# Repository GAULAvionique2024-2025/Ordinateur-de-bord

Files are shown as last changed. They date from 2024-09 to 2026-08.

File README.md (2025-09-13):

# Ordinateur de Bord GAUL — Branche ODBlix

Bienvenue dans la branche **ODBlix** du projet *Ordinateur de Bord* de GAULAvionique.  
Cette version propose une architecture alternative / expérimentale / allégée (ajuster selon la réalité) du système embarqué, avec une organisation de dossier particulière et des versions de firmware différentes.

---

## Table des Matières

1. [Description générale](#description-générale)  
2. [Composants intégrés](#composants-intégrés)  
3. [Structure de la branche / organisation des dossiers](#structure-de-la-branche--organisation-des-dossiers)  
4. [Détails des versions](#détails-des-versions)  
5. [Installation & Build](#installation--build)  
6. [Roadmap & Fonctionnalités à venir](#roadmap--fonctionnalités-à-venir)  
7. [Contributeurs](#contributeurs)

---

## Description générale

La branche **ODBlix** propose une déclinaison de l’Ordinateur de Bord standard, conçue pour :

- réduire la complexité / le poids / la consommation (ajuster selon le but),
- tester de nouvelles versions expérimentales de firmware / de drivers,
- faciliter les comparaisons entre versions (V1, V3, etc.) dans un même environnement.

Elle s’appuie sur les mêmes principes que l’Ordinateur de Bord principal : collecte de données, télémétrie, enregistrement, communication, etc.

---

## Composants intégrés

ODBlix intègre (liste à vérifier selon ce qui est actif) :

- Accéléromètre / gyroscope  
- Capteur de pression / altimètre  
- Module GPS (position)  
- Lecteur de carte SD pour enregistrement de données  
- Module de communication radio pour la transmission vers le sol  
- Buzzer ou indicateurs sonores pour alertes / statuts  
- (Optionnel) capteurs auxiliaires selon version (température, orientation additionnelle, etc.)

---

## Structure de la branche / organisation des dossiers

Voici les principaux dossiers / fichiers, et leur rôle respectif :

| Dossier / fichier | Description |
|---|---|
| `ODB_V1/` | Version 1 du firmware / hardware : fonctionnalités de base, stabilité, tests initiaux. |
| `ODB_V2/` | Version 2 du firmware / hardware : stabilité, correction des problèmes de la V1 |
| `ODB_V3/` | Version 3 : ajout de fonctionnalités avancées / optimisation ; comparatif avec V2. |

---

## Détails des versions

- **ODB_V1** : version de base. Priorité sur la fiabilité et sur la collecte de données simples. Moins de fonctionnalités, interface minimale et non fonctionnel.
- **ODB_V2** : version de base. Priorité sur la fiabilité et sur la collecte de données simples. Moins de fonctionnalités, interface minimale avec correctifs, mais non testé.    
- **ODB_V3** : version plus avancée. Ajout / amélioration de modules, optimisations (ex : consommation, vitesse, taille), peut-être nouvelles fonctionnalités / capteurs.
- 
---

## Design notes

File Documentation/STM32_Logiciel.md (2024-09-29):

# 🧩 **Prise en main STM32CubeIDE**

## **STM32CubeIDE**

<div style="display: flex; justify-content: space-around;">
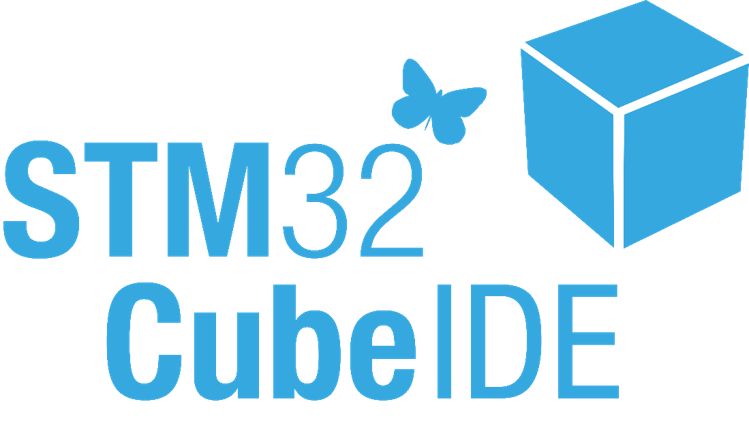
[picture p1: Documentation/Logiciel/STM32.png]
ODB1
  
</div>

STM32CubeIDE est un environnement de développement intégré (IDE) tout-en-un, qui inclut un compilateur, un éditeur de code, des outils de configuration de périphériques, ainsi que des outils de débogage.

## **Table des matières**
1. [Installation de STM32CubeIDE](#1-installation-de-stm32cubeide)
2. [Ouvrir un projet existant à partir de fichiers système](#2-ouvrir-un-projet-existant-à-partir-de-fichiers-système)
3. [Exploration de la structure des fichiers](#3-exploration-de-la-structure-des-fichiers)
4. [Consoles Problems et Tasks](#4-consoles-problems-et-tasks)
5. [Outils de Build](#5-outils-de-build)
6. [Débogage avec ST-Link](#6-débogage-avec-st-link)
7. [Exécution et Flash du programme](#7-exécution-et-flash-du-programme)
8. [Autres indications importantes pour STM32CubeIDE](#8-autres-indications-importantes-pour-stm32cubeide)

## ⬇️ **1. Installation de STM32CubeIDE**
Avant tout, vous devez installer STM32CubeIDE. Il est [téléchargeable](https://www.st.com/en/development-tools/stm32cubeide.html) gratuitement sur le site de STMicroelectronics.
## 📂 **2. Ouvrir un projet existant à partir de fichiers système**

### Cloner un dépôt Git
- Si vous travaillez à partir d’un dépôt Git, clonez-le dans le répertoire choisi en utilisant un client Git comme **Git Bash** ou un autre outil tel que **GitHub Desktop**.

### Ouvrir le projet dans STM32CubeIDE
- **Lancer STM32CubeIDE**.
- Allez dans **File > Open Projects from File System...**.
- Cliquez sur **Directory** et naviguez jusqu'au dossier cloné (celui contenant les fichiers de votre projet STM32).
- STM32CubeIDE analysera les fichiers et proposera les projets disponibles. Sélectionnez le projet pertinent.

### Projets basés sur `.ioc` (STM32CubeMX)
Si votre projet contient un fichier `.ioc`, c'est un fichier de configuration utilisé par **STM32CubeMX**, qui est intégré dans STM32CubeIDE. Ouvrez ce fichier pour reconfigurer les périphériques et générer des fichiers de code source (HAL, LL, etc.) automatiquement (utile au début, mais le projet est développé en low level **LL**).

## 🔍 **3. Exploration de la structure des fichiers**
Lorsque le projet est chargé, STM32CubeIDE organise les fichiers dans l'onglet **Project Explorer**, habituellement tout à gauche de l'interface :

### Header files (.h)
- Vous trouverez ces fichiers dans le dossier **Inc/** ou **include/**. Ils contiennent les définitions, les prototypes de fonctions et les déclarations des structures de données.

### Source files (.c)
- Les fichiers source se trouvent dans le dossier **Src/**. C’est là où vous écrivez le code source (implémentation des fonctions, logique principale, etc.).

### Drivers
- Ce dossier contient des fichiers relatifs aux bibliothèques STM32, telles que les fichiers HAL (Hardware Abstraction Layer), CMSIS (Cortex Microcontroller Software Interface Standard) et LL (Low Layer).

### Middlewares
- Si le projet utilise des bibliothèques de middleware comme FreeRTOS, USB, ou LwIP, ces fichiers seront stockés ici.

## 📋 **4. Consoles "Problems" et "Tasks"**

### Console "Problems"
- La console **Problems** affiche les erreurs et avertissements détectés dans votre projet. Elle vous aide à identifier rapidement les problèmes de compilation et de configuration. 
- Vous pouvez accéder à cette console via **Window > Show View > Problems**.

### Console "Tasks"
- La console **Tasks** vous permet de gérer les tâches, les rappels et les TODOs (//TODO) dans votre code. Vous pouvez y ajouter des notes ou des éléments à vérifier. 
- Accédez à cette console via **Window > Show View > Tasks**. Cela vous aide à garder une trace des éléments à améliorer ou des fonctionnalités à implémenter dans votre projet à travers le code.

## 🛠️ **5. Outils de Build**
STM32CubeIDE utilise **GNU Make** pour construire (compiler et lier) le projet. Voici les étapes pour réaliser le build de votre projet :

### Build simple
- Pour compiler le projet, cliquez sur le bouton 🔨 (en haut) ou utilisez le raccourci **CTRL+B**.
- Cela déclenchera le processus de compilation, et vous verrez les sorties dans la console de build (en bas de l'IDE). Si des erreurs ou des avertissements sont générés, vous pourrez les consulter ici.

### Configuration du build
- Vous pouvez ajuster les options de compilation dans **Project > Properties > C/C++ Build > Settings**. Vous pouvez, par exemple, modifier les optimisations du compilateur (par défaut -0n) ou ajuster les options de debug.

## 🐛 **6. Débogage avec ST-Link**

### Connexion du ST-Link
Le **ST-Link** est un outil de débogage et de programmation pour les microcontrôleurs STM32.

1. **Brancher** le ST-Link à la carte STM32 et à votre PC via USB.
2. STM32CubeIDE détecte normalement automatiquement le ST-Link connecté.

### Configuration de l'interface de débogage
- Allez dans **Run > Debug Configurations**.
- Choisissez **STM32 Cortex-M C/C++ Application** puis sélectionnez la configuration de débogage.
- Dans l'onglet **Debugger**, assurez-vous que le **ST-Link** est sélectionné comme interface de débogage.
  - Interface : **SWD (Serial Wire Debug)** est généralement le protocole utilisé.
  - Console : **SWV ITM Data Console** est utile lorsque des données sont **printf** sur le bus USB de l'ordinateur connecté au Debugger.

### Lancer le débogage
- Cliquez sur l'icône 🐞 pour démarrer le mode débogage. Cela compile le projet (si nécessaire), télécharge le binaire sur la carte, et arrête le processeur au point d'entrée (généralement dans `main()`).
- Vous pouvez ensuite utiliser des fonctionnalités comme les **points d'arrêt**, **step into/over** (avancer pas à pas dans le code), inspecter les **variables**, la **mémoire**, les **registres**, etc.

## 🏃‍♂️ **7. Exécution et Flash du programme**

### Lancer le programme sans débogage
- Pour exécuter directement votre programme sans mode debug, cliquez sur le bouton ▶️ (vert) ou utilisez **CTRL+F11**.
- Le binaire sera flashé sur la carte et le programme démarrera immédiatement après le téléchargement.

## 🔔 **8. Autres indications importantes pour STM32CubeIDE**

### Générer du code avec STM32CubeMX
- Si vous avez un fichier `.ioc`, vous pouvez l'ouvrir et ajouter des périphériques, ajuster la configuration (comme les GPIO, Timers, UART, I2C, etc.), et générer à nouveau le code. STM32CubeIDE synchronisera automatiquement les fichiers générés avec votre projet.

### Exploration de la documentation
- STM32CubeIDE fournit une intégration avec **la documentation CMSIS** et **les fichiers HAL/LL**. Faites un **CTRL+LMB** sur une fonction pour accéder directement à sa définition ou documentation dans le code.

---

🔙 Retour à la [page principale](../README.md)

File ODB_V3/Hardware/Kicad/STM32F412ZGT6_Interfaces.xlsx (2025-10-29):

Interface | #No | Horloge | Vitesse max | Fonctions | Broche | GPIO Mode | AFR | Fonctionnalités utiles | Informations
SPI | 1 | APB2 | 50Mbits/s | SCK | PA5 | Alternate | AF5 | FSMC | 8-16bits data bus width
 |  |  |  | MISO | PA6 | Alternate | AF5 |  | FSMC_CLK 90MHz
 |  |  |  | MOSI | PA7 | Alternate | AF5 | CRC | 32bits embdeed
 |  |  |  | NSS (CS) | PA4 | Alternate | AF5 | DMA | DMA1, DMA2 8 channels
 | 2 | APB1 | 25Mbits/s | SCK | PB13 | Alternate | AF5 |  | circular buffer embdeed
 |  |  |  | MISO | PB14 | Alternate | AF5 | NVIC | internal interrupt 16 lines
 |  |  |  | MOSI | PB15 | Alternate | AF5 | EXTI | external interrupt
 |  |  |  | NSS (CS) | PB12 | Alternate | AF5 | Timers | TIM1 - 4 channels | PA8,..,PA11
 | 3 | APB1 | 25Mbits/s | SCK | PB3 | Alternate | AF6 |  | TIM2 - 4 channel | PA0,…,PA3
 |  |  |  | MISO | PB4 | Alternate | AF6 |  | TIM3 - 4 chhanels | PC6,…,PC9
 |  |  |  | MOSI | PB5 | Alternate | AF6 |  | TIM4 - 4 chhanels | PB6,…, PB9
 |  |  |  | NSS (CS) | PA15 | Alternate | AF6 |  | TIM5 - 4 chhanels | PA0,…,PA3
 | 4 | APB2 | 50Mbits/s | SCK | PE12 | Alternate | AF5 |  | TIM8 - 4 chhanels | PC6,…,PC9
 |  |  |  | MISO | PE13 | Alternate | AF5 |  | TIM9 - 2 chhanels | PA2, PA3
 |  |  |  | MOSI | PE14 | Alternate | AF5 |  | TIM10 | PB8
 |  |  |  | NSS (CS) | PE4 | Alternate | AF5 |  | TIM11 | PB9
 | 5 | APB2 | 50Mbits/s | SCK | PB0 | Alternate | AF6 |  | TIM12 - 2 chhanels | PB14,PB15
 |  |  |  | MISO | PA12 | Alternate | AF6 |  | TIM13 | PA6
 |  |  |  | MOSI | PA10 | Alternate | AF6 |  | TIM14 | PA7
 |  |  |  | NSS (CS) | PA4 | Alternate | AF6
UART | 1 | APB2 | 12.5Mbit/s | TX | PA9 | Alternate | AF7
 |  |  |  | RX | PA10 | Alternate | AF7
 |  |  |  | CTS | PA11 | Alternate | AF7
 |  |  |  | RTS | PA12 | Alternate | AF7
 |  |  |  | CK | PA8 | Alternate | AF7 | RTC
 | 2 | APB1 | 6.25Mbit/s | TX | PD5 | Alternate | AF7
 |  |  |  | RX | PD6 | Alternate | AF7
 |  |  |  | CTS | PD3 | Alternate | AF7
 |  |  |  | RTS | PD4 | Alternate | AF7
 |  |  |  | CK | PD7 | Alternate | AF7
 | 3 | APB1 | 6.25Mbit/s | TX | PD8 / PB10 | Alternate | AF7 | Interfaces Composants |  |  | Vitesse
 |  |  |  | RX | PD9 / PB11 | Alternate | AF7 | BNO055 (UART-I2C) | I2C1 |  | 1MHz
 |  |  |  | CTS | PD11 | Alternate | AF7 | ADXL382-2BCCZ-RL7 (I2C) | I2C3 |  | 400kHz
 |  |  |  | RTS | PD12 | Alternate | AF7 | ZED-F9P-15B / L76LM33 (UART) | UART6 |  | 12,5Mbit/s
 |  |  |  | CK | PD10 | Alternate | AF7 | MS5803 (SPI) | SPI1 |  | 50Mbits/s
 | 6 | APB2 | 12.5Mbit/s | TX | PC6 | Alternate | AF8 | HM-11 (UART) | UART2 |  | 6,25Mbit/s
 |  |  |  | RX | PC7 | Alternate | AF8 | RFD900x (UART) + RF connector | UART1 |  | 12,5Mbit/s
 |  |  |  | CTS | PG13 | Alternate | AF8 | W25Q512JVEIQ (SPI) | QuadSPI |  | 50Mbits/s
 |  |  |  | RTS | PG12 | Alternate | AF8 | SD Card (SPI) | SPI5 |  | 50Mbits/s
 |  |  |  | CK | PG7 | Alternate | AF8 | ODB <-> Beacon | I2C2 |  | 400kHz
I2C | 1 | APB1 | ~400kHz ~1MHz | SCL | PB6 | Alternate | AF4 | MAX6612MXK | ADC - Channel10 |  | -
 |  |  |  | SDA | PB7 | Alternate | AF4 | SMTB-0927-TW-R | TIM4 - Channel1 |  | -
 |  |  |  | SMBA | PB5 | Alternate | AF4 | Alimentation Vin | ADC - Channel11 |  | -
 | 2 | APB1 | ~400kHz | SCL | PB10 / PF1 | Alternate | AF4 | Alimentation 5V | ADC - Channel12 |  | -
 |  |  |  | SDA | PB11 / PF0 | Alternate | AF4 | Alimentation 3V3 | ADC - Channel13 |  | -
 |  |  |  | SMBA | PB12 / PF2 | Alternate | AF4 | Continuité Pyros armé | ADC - Channel0 |  | -
 | 3 | APB1 | ~400kHz | SCL | PA8 | Alternate | AF4 | Continuité Pyro1 | ADC - Channel1 |  | -
 |  |  |  | SDA | PC9 | Alternate | AF4 | Continuité Pyro2 | ADC - Channel4 |  | -
 |  |  |  | SMBA | PA9 | Alternate | AF4 | Continuité Pyro3 | ADC - Channel5 |  | -
ADC | 0 | APB2 | - | 12bits | PA0 | Analog | - | Continuité Pyro4 | ADC - Channel8 |  | -
 | 1 | APB2 | - | 12bits | PA1 | Analog | - | EXTEND
 | 2 | APB2 | - | 12bits | PA2 | Analog | - | UART3
 | 3 | APB2 | - | 12bits | PA3 | Analog | - | SPI2
 | 4 | APB2 | - | 12bits | PA4 | Analog | -
 | 5 | APB2 | - | 12bits | PA5 | Analog | -
 | 6 | APB2 | - | 12bits | PA6 | Analog | -
 | 7 | APB2 | - | 12bits | PA7 | Analog | -
 | 8 | APB2 | - | 12bits | PB0 | Analog | -
 | 9 | APB2 | - | 12bits | PB1 | Analog | -
 | 10 | APB2 | - | 12bits | PC0 | Analog | -
 | 11 | APB2 | - | 12bits | PC1 | Analog | - | *Datasheet p.66
 | 12 | APB2 | - | 12bits | PC2 | Analog | - | *Datasheet p.17
 | 13 | APB2 | - | 12bits | PC3 | Analog | -
 | 14 | APB2 | - | 12bits | PC4 | Analog | -
 | 15 | APB2 | - | 12bits | PC5 | Analog | -
FSMC | D0 | - | - | Data | PD14 | Alternate | AF12
 | D1 | - | - | Data | PD15 | Alternate | AF12
 | D2 | - | - | Data | PD0 | Alternate | AF12
 | D3 | - | - | Data | PD1 | Alternate | AF12
 | D4 | - | - | Data | PE7 | Alternate | AF12
 | D5 | - | - | Data | PE8 | Alternate | AF12
 | D6 | - | - | Data | PE9 | Alternate | AF12
 | D7 | - | - | Data | PE10 | Alternate | AF12
 | ? | - | - | Command Latch | PD11 | Alternate | AF12
 | ? | - | - | Address Latch | PD12 | Alternate | AF12
 | NWE | - | - | Write Enable | PD5 | Alternate | AF12
 | NOE | - | - | Read Enable | PD4 | Alternate | AF12
 | NE(1234) | - | - | Chip Enable | PD7 | Alternate | AF12
 | NWAIT | - | - | Ready/Busy Signal | PG6 | Push-Pull | -
 | CLK
 | NL
 | NBL(01)

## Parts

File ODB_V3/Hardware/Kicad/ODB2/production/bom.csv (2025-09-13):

Designator | Footprint | Quantity | Value | LCSC Part #
1V8_C1, 1V8_C4, 3V3_C1, 3V7_C1, 5V_C1, 5V_C3, 7V4_C1, BEACON_C1, BT_C1, DECOUPLE_C1, DECOUPLE_C14, MEM_C1, USB_C3 | 0603 | 13 | 10uf
1V8_C2, 1V8_C3, 3V3_C2, 3V3_C4, 3V7_C2, 5V_C2, 5V_C4, 7V4_C3, 7V4_C4, BT_C2, DECOUPLE_C10, DECOUPLE_C11, DECOUPLE_C12, DECOUPLE_C13, DECOUPLE_C17, DECOUPLE_C2, DECOUPLE_C3, DECOUPLE_C4, DECOUPLE_C5, DECOUPLE_C6, DECOUPLE_C7, DECOUPLE_C8, DECOUPLE_C9, GPS_C1, ICM_C1, ICM_C2, PYROS_C1, PYROS_C2, RST_C1, USB_C1 | 0603 | 30 | 100nf
1V8_R1 | 0603 | 1 | 12.2k
1V8_R2, 7V4_R4, 7V4_R5, BOOT_R2, BT_R1, PYROS_R15, PYROS_R16, PYROS_R2, PYROS_R5, PYROS_R7, PYROS_R8, RST_R1 | 0603 | 12 | 10k
1V8_REG1 | DFN-8-1EP_3x3mm_P0.65mm_EP1.55x2.4mm | 1 | MCP1727-1802xMF
3V3_C3, 7V4_C2 | 0603 | 2 | 33uf
3V3_L1 | IND_LQH3NPN3R3MMEL | 1 | 3.3uH
3V3_LED1, 5V_LED1, BATT7V4_L1, LED_7V4ENABLE1, PYROS_LED1, PYROS_LED2, PYROS_LED4 | 0603 | 7 | GREEN
3V3_PWRSWITCH1 | VSON-10-1EP_3x3mm_P0.5mm_EP1.65x2.4mm | 1 | TPS61201DRCR
3V3_R1 | 0603 | 1 | 3M 1%
3V3_R2 | 0603 | 1 | 249k 1%
3V3_R3, 5V_R1, 7V4_R3, BOOT_R1, BT_R2, BUZ_R1, BUZ_R2, CLED_R1, MEM_R1, PYROS_R1, PYROS_R14, PYROS_R17, PYROS_R18, PYROS_R19, PYROS_R6 | 0603 | 15 | 1k5
3V7_FUZE1 | 1210 | 1 | 0ZCH0075AF2E (750ma)
3V7_MOSFET1 | SOT-23-3 | 1 | PJA3411_R1_00001
3V7_R1, 7V4_R1 | 0603 | 2 | 100k 1%
3V7_R2 | 0603 | 1 | 30k 1%
3V7_R3 | 0603 | 1 | 100k
5V_REG1 | TO-263-3_TabPin2 | 1 | LM1085-5.0
7V4_L1 | 2920 | 1 | 2920L700/12MR
7V4_MOSFET1 | PG-TO252AA_INF | 1 | IRFR5505TRPBF
7V4_NPN1, BUZ_NPN1, PYROS_NPN1, PYROS_NPN2 | SOT-23 | 4 | MMBT3904
7V4_R2 | 0603 | 1 | 64k 1%
7V4_R8 | 0603 | 1 | 1k
BARO_C1 | 0805 | 1 | 100nF
BATT7V4_D2 | D_SOD-123 | 1 | MMSZ4678-TP
BATT7V4_R1, BATT7V4_R2 | 0603 | 2 | 68 1%
BT_LED1 | 0603 | 1 | BLUE
BUZ_BUZZER1 | SMTB-0927-TW-R_PUI | 1 | SMTB-0927-TW-R
CLED_LED1 | 0603 | 1 | RED
COUPLING_FB1, USB_FB1 | 0805 | 2 | 120R
CRYSTAL_C1, CRYSTAL_C2 | 0603 | 2 | 8pF
CRYSTAL_R1 | 0603 | 1 | 0R
CRYSTAL_Y1 | XTAL_TSX-3225_26.0000MF09Z-AC0 | 1 | 26MHz
D3 | D_SOD-123 | 1 | BUZ_D_Schottky
DECOUPLE_C15, DECOUPLE_C16 | 0603 | 2 | 10nF
E1 | HM-10 | 1 | HM-10
GPS_L1 | 0805 | 1 | 100nH
GPS_R1 | 0603 | 1 | 10R
J4 | SMA_Wurth_60312002114503_Vertical | 1 | RF2-04A-T-00-50-G
J5 | SMA_Wurth_60312002114503_Vertical | 1 | RFM_Conn_Coaxial
PYROS_AND1 | SOIC-14_3.9x8.7mm_P1.27mm | 1 | SN74HC08DR
PYROS_J1 | TerminalBlock_RND_205-00012_1x02_P5.00mm_Horizontal | 1 | Pyro_Main
PYROS_J2 | TerminalBlock_RND_205-00012_1x02_P5.00mm_Horizontal | 1 | Pyro_Drogue
PYROS_MOSFET1, PYROS_MOSFET2 | TDSON-8-1 | 2 | CSD17310Q5A
PYROS_PNP1 | SOT-23 | 1 | BC857
PYROS_R3 | 0603 | 1 | 68R ±1%
PYROS_R4 | 0603 | 1 | 390k ±1%
SW_J1 | PinHeader_1x05_P2.00mm_Vertical | 1 | SYS_Conn_01x05_Socket
U1 | LQFP-144_20x20mm_P0.5mm | 1 | STM32F412ZGTx
U10 | SON127P600X800X80-9N | 1 | W25Q512JVEIQ
U2 | SOT-23-5 | 1 | TLV2371DBV
U3 | SC-74A_SOT753_NEX | 1 | 74LV1T87GVH
U5 | L76_QWS | 1 | L76L-M33
U6 | ICM-L | 1 | ICM-20948
U7 | MS5803-01BA01_TEC | 1 | MS580301BA01-00
U9 | RFM22b-S2 | 1 | RFM22B
USB_BUS1 | USB_Micro-B_Molex-105017-0001 | 1 | USB_B_Micro
USB_C2 | 0603 | 1 | 1uf
USB_CONNECTOR1 | SOT-666 | 1 | USBLC6-2P6
USB_D1 | D_SOD-123 | 1 | B260A-13-F
VCAP_C1, VCAP_C2 | 0603 | 2 | 4.7uF

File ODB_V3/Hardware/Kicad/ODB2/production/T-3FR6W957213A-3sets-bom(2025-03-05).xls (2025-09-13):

PCBWay Bom Quotation, Product No.:T-3FR6W957213A
Item # | *Designator | *Qty | *Mfg Part # | Description / Value | *Package/Footprint | *Unit Price(3 sets) | *Total | *Delivery Time | *Actual Purchase Mfg Part # | *PCBWay Note | Customer Reply | PCBWay Update
1 | 1V8_C1, 1V8_C4, 3V3_C1, 3V7_C1, 5V_C1, 5V_C3, 7V4_C1, BEACON_C1, BT_C1, DECOUPLE_C1, DECOUPLE_C14, MEM_C1, USB_C3 | 13 | C1608X5R1A106M080AC | 10uf | Capacitor_SMD:C_0603_1608Metric | $0.319 | $12.441 | 7-10 Workdays
2 | 1V8_C2, 1V8_C3, 3V3_C2, 3V3_C4, 3V7_C2, 5V_C2, 5V_C4, 7V4_C3, 7V4_C4, BT_C2, DECOUPLE_C10, DECOUPLE_C11, DECOUPLE_C12, DECOUPLE_C13, DECOUPLE_C17, DECOUPLE_C2, DECOUPLE_C3, DECOUPLE_C4, DECOUPLE_C5, DECOUPLE_C6, DECOUPLE_C7, DECOUPLE_C8, DECOUPLE_C9, GPS_C1, ICM_C1, ICM_C2, PYROS_C1, PYROS_C2, RST_C1, USB_C1 | 30 | C1608X5R1A106M080AC | 100nf | Capacitor_SMD:C_0603_1608Metric | $0.319 | $28.710 | 7-10 Workdays |  | The correct capacitance value for the listed Part Number [C1608X5R1A106M080AC] is indeed [10uF], not [100nF].Please confirm. | CC0603KRX7R7BB104
3 | 1V8_R1 | 1 | CRCW060312K2FKEA1 | 12.2k | Resistor_SMD:R_0603_1608Metric | $0.092 | $0.276 |  | CRCW060312K2FKEA | The part we will supply is CRCW060312K2FKEA OK？ | Remove 1V8_R1
4 | 7V4_R4, 7V4_R5, BOOT_R2, BT_R1, PYROS_R15, PYROS_R16, PYROS_R2, PYROS_R5, PYROS_R7, PYROS_R8, RST_R1 | 12 | CRCW060310K0FKEA | 10k | Resistor_SMD:R_0603_1608Metric | $0.044 | $1.584 | 7-10 Workdays |  |  | Remove 1V8_R2
5 | 1V8_REG1 | 1 | MCP1727-1802xMF | MCP1727-1802xMF | DFN-8-1EP_3x3mm_P0.65mm_EP1.55x2.4mm | $1.633 | $4.899 | 7-10 Workdays | MCP1727-1802E/MF | The part we will supply is MCP1727-1802E/MF OK？ | OK
6 | 3V3_C3, 7V4_C2 | 2 | C1608X5R1A336M080AC | 33uf | Capacitor_SMD:C_0603_1608Metric | $0.189 | $1.134
7 | 3V3_L1 | 1 | LQH3NPN3R3MMEL | 3.3uH | IND_LQH3NPN3R3MMEL | $0.643 | $1.929 | 7-10 Workdays
8 | 3V3_LED1, 5V_LED1, BATT7V4_L1, LED_7V4ENABLE1, PYROS_LED1, PYROS_LED2, PYROS_LED4 | 7 |  | GREEN | LED_SMD:LED_0603_1608Metric | $0.020 | $0.420 |  | NCD0603G3 | The part we will supply is NCD0603G3 OK？ | OK
9 | 3V3_PWRSWITCH1 | 1 | TPS61201DRCR | TPS61201DRCR | VSON-10-1EP_3x3mm_P0.5mm_EP1.65x2.4mm | $3.019 | $9.057
10 | 3V3_R1 | 1 | CRCW06033M00FKEA | 3M 1% | Resistor_SMD:R_0603_1608Metric | $0.092 | $0.276
11 | 3V3_R2 | 1 | CRCW0603249KFKEA | 249k 1% | Resistor_SMD:R_0603_1608Metric | $0.092 | $0.276
12 | 3V3_R3, 5V_R1, 7V4_R3, BOOT_R1, BT_R2, BUZ_R1, BUZ_R2, CLED_R1, MEM_R1, PYROS_R1, PYROS_R14, PYROS_R17, PYROS_R18, PYROS_R19, PYROS_R6 | 15 | CRCW06031K50FKEA | 1k5 | Resistor_SMD:R_0603_1608Metric | $0.045 | $2.025 | 7-10 Workdays
13 | 3V7_FUZE1 | 1 | 0ZCH0075AF2E (750ma) | 0ZCH0075AF2E (750ma) | Fuse_1210_3225Metric | $0.658 | $1.974 | 7-10 Workdays | 0ZCH0075AF2E | The part we will supply is 0ZCH0075AF2E OK？ | OK
14 | 3V7_MOSFET1 | 1 | PJA3411_R1_00001 | PJA3411_R1_00001 | SOT-23-3 | $0.403 | $1.209 | 7-10 Workdays
15 | 3V7_R1, 7V4_R1 | 2 | CRCW0603100KFKEA | 100k 1% | Resistor_SMD:R_0603_1608Metric | $0.052 | $0.312 | 7-10 Workdays
16 | 3V7_R2 | 1 | CRCW060330K0FKEA | 30k 1% | Resistor_SMD:R_0603_1608Metric | $0.092 | $0.276
17 | 3V7_R3 | 1 | CRCW0603100KFKEA | 100k | Resistor_SMD:R_0603_1608Metric | $0.052 | $0.156 | 7-10 Workdays
18 | 5V_REG1 | 1 | LM1085-5.0 | LM1085-5.0 | TO-263-3_TabPin2 |  |  |  |  | [It's out of stock. Please recommend substitutes or you can supply this part to us.] | LM1085ISX-5.0/NOPB (if you have it), else will solder it ourself
19 | 7V4_L1 | 1 | 2920L700/12MR | 2920L700/12MR | Fuse_2920_7451Metric | $0.594 | $1.782
20 | 7V4_MOSFET1 | 1 | IRFR5505TRPBF | IRFR5505TRPBF | PG-TO252AA_INF | $0.704 | $2.112
21 | 7V4_NPN1, BUZ_NPN1, PYROS_NPN1, PYROS_NPN2 | 4 | MMBT3904 | MMBT3904 | SOT-23 | $0.094 | $1.128 | 7-10 Workdays |  | The part we will supply is MMBT3904 made by Diotec OK？ | OK
22 | 7V4_R2 | 1 | CRCW060364K0FKEA | 64k 1% | Resistor_SMD:R_0603_1608Metric | $0.092 | $0.276
23 | 7V4_R8 | 1 | CRCW06031K00FKEA | 1k | Resistor_SMD:R_0603_1608Metric | $0.092 | $0.276
24 | BARO_C1 | 1 | C2012X5R1A107M125AB | 100nF | Capacitor_SMD:C_0805_2012Metric |  |  |  |  | [It's out of stock. Please recommend substitutes or you can supply this part to us.] | Change BARO_C1's part number to CC0603KRX7R7BB104 (same as item #2)
25 | BATT7V4_D2 | 1 | MMSZ4678-TP | MMSZ4678-TP | D_SOD-123 | $0.134 | $0.402 | 7-10 Workdays
26 | BATT7V4_R1, BATT7V4_R2 | 2 | CRCW060368R1FKEA | 68 1% | Resistor_SMD:R_0603_1608Metric | $0.052 | $0.312 | 7-10 Workdays
27 | BT_LED1 | 1 |  | BLUE | LED_SMD:LED_0603_1608Metric | $0.067 | $0.201 |  | NCD0603B5 | The part we will supply is NCD0603B5 OK？ | OK
28 | BUZ_BUZZER1 | 1 | SMTB-0927-TW-R | SMTB-0927-TW-R | SMTB-0927-TW-R_PUI | $1.741 | $5.223 | 7-10 Workdays
29 | CLED_LED1 | 1 |  | RED | LED_SMD:LED_0603_1608Metric | $0.088 | $0.264 |  | NCD0603R1 | The part we will supply is NCD0603R1 OK？ | OK
30 | COUPLING_FB1, USB_FB1 | 2 | CRCW0805120RFKEA | 120R | Resistor_SMD:R_0805_2012Metric | $0.092 | $0.552
31 | CRYSTAL_C1, CRYSTAL_C2 | 2 | C1608X5R1A080M080AC | 8pF | Capacitor_SMD:C_0603_1608Metric |  |  |  |  | [It's out of stock. Please recommend substitutes or you can supply this part to us.] | CC0603DRNPO9BN8R0
32 | CRYSTAL_R1 | 1 | CRCW06030000Z0EA | 0R | Resistor_SMD:R_0603_1608Metric | $0.092 | $0.276
33 | CRYSTAL_Y1 | 1 | TSX-3225_26.0000MF09Z-ACO | 26MHz | XTAL_TSX-3225_26.0000MF09Z-AC0 |  |  |  |  | [It's out of stock. Please recommend substitutes or you can supply this part to us.] | TSX-3225 26.0000MF09Z-AC3 (if you have it), else will solder it ourself
34 | D3 | 1 | B260A-13-F | BUZ_D_Schottky | D_SOD-123 | $0.341 | $1.023
35 | DECOUPLE_C15, DECOUPLE_C16 | 2 | C1608X5R1A103M080AC | 10nF | Capacitor_SMD:C_0603_1608Metric | $0.189 | $1.134
36 | E1 | 1 | HM-10 | HM-10 | HM-10 |  |  |  |  | [It's out of stock. Please recommend substitutes or you can supply this part to us.] | We will solder it ourself
37 | GPS_L1 | 1 | LQH2MCN101M02L | 100nH | Inductor_SMD:L_0805_2012Metric | $0.630 | $1.890
38 | GPS_R1 | 1 | CRCW060310R0FKEA | 10R | Resistor_SMD:R_0603_1608Metric | $0.092 | $0.276
39 | J4 | 1 | 60312002114503 | RF2-04A-T-00-50-G | SMA_Wurth_60312002114503_Vertical | $7.296 | $21.888 | 7-10 Workdays |  | The quoted part number is [60312002114503], not [RF2-04A-T-00-50-G] as specified in description,OK? | We will solder it ourself
40 | J5 | 1 | 60312002114503 | RF2-04A-T-00-50-G | SMA_Wurth_60312002114503_Vertical | $7.296 | $21.888 | 7-10 Workdays |  | The quoted part number is [60312002114503], not [RF2-04A-T-00-50-G] as specified in description,OK? | We will solder it ourself
41 | PYROS_AND1 | 1 | SN74HC08DR | SN74HC08DR | SOIC-14_3.9x8.7mm_P1.27mm | $0.244 | $0.732 | 7-10 Workdays
42 | PYROS_J1 | 1 |  | Pyro_Main | TerminalBlock_RND_205-00012_1x02_P5.00mm_Horizontal |  |  |  |  | pls provide exact part number and brand | We will solder it ourself
43 | PYROS_J2 | 1 |  | Pyro_Drogue | TerminalBlock_RND_205-00012_1x02_P5.00mm_Horizontal |  |  |  |  | pls provide exact part number and brand | We will solder it ourself
44 | PYROS_MOSFET1, PYROS_MOSFET2 | 2 | CSD17310Q5A | CSD17310Q5A | TDSON-8-1 | $0.904 | $5.424 | 7-10 Workdays
45 | PYROS_PNP1 | 1 | BC857 | BC857 | SOT-23 | $0.414 | $1.242 | 7-10 Workdays |  | The part we will supply is BC857 made by Rectron OK？ | OK
46 | PYROS_R3 | 1 | CRCW060368R0FKEA | 68R ±1% | Resistor_SMD:R_0603_1608Metric | $0.092 | $0.276
47 | PYROS_R4 | 1 | CRCW0603390KFKEA | 390k ±1% | Resistor_SMD:R_0603_1608Metric | $0.092 | $0.276
48 | SW_J1 | 1 |  | SYS_Conn_01x05_Socket | PinHeader_1x05_P2.00mm_Vertical |  |  |  |  | pls provide exact part number and brand | We will solder it ourself
49 | U1 | 1 | STM32F412ZGT6 | STM32F412ZGTx | LQFP-144_20x20mm_P0.5mm | $7.748 | $23.244
50 | U10 | 1 | W25Q512JVEIQ | W25Q512JVEIQ | SON127P600X800X80-9N | $4.629 | $13.887
51 | U2 | 1 | TLV2371DBV | TLV2371DBV | SOT-23-5 |  |  |  |  | [It's out of stock. Please recommend substitutes or you can supply this part to us.] | TLV2371IDBVR
52 | U3 | 1 | 74LV1T87GVH | 74LV1T87GVH | SC-74A_SOT753_NEX | $0.421 | $1.263 | 7-10 Workdays
53 | U5 | 1 | L76L-M33 | L76L-M33 | L76_QWS | $13.283 | $39.849
54 | U6 | 1 | ICM-20948 | ICM-20948 | ICM-L | $5.031 | $15.093
55 | U7 | 1 | MS580301BA01-00 | MS580301BA01-00 | MS5803-01BA01_TEC | $29.855 | $89.565 | 7-10 Workdays
56 | U9 | 1 | RFM22B | RFM22B | RFM22b-S2 |  |  |  |  | [It's out of stock. Please recommend substitutes or you can supply this part to us.] | We will solder it ourself
57 | USB_BUS1 | 1 | 1050170001 | USB_B_Micro | USB_Micro-B_Molex-105017-0001 | $0.664 | $1.992
58 | USB_C2 | 1 | C1608X5R1A105M080AC | 1uf | Capacitor_SMD:C_0603_1608Metric | $0.189 | $0.567
59 | USB_CONNECTOR1 | 1 | USBLC6-2P6 | USBLC6-2P6 | SOT-666 | $0.463 | $1.389 |  |  | The part we will supply is USBLC6-2P6 made by ST OK？ | OK
60 | USB_D1 | 1 | B260A-13-F | B260A-13-F | D_SOD-123 | $0.341 | $1.023
61 | VCAP_C1, VCAP_C2 | 2 | C1608X5R1A475M080AC | 4.7uF | Capacitor_SMD:C_0603_1608Metric | $0.189 | $1.134
 |  |  |  |  |  | Component Cost | $324.81
 |  |  |  |  |  | Assembly Cost
 |  |  |  |  |  | PCB Cost
 |  |  |  |  |  | V0 Member 0% off | $0.00
 |  |  |  |  |  | All Total 3 Sets | $324.81

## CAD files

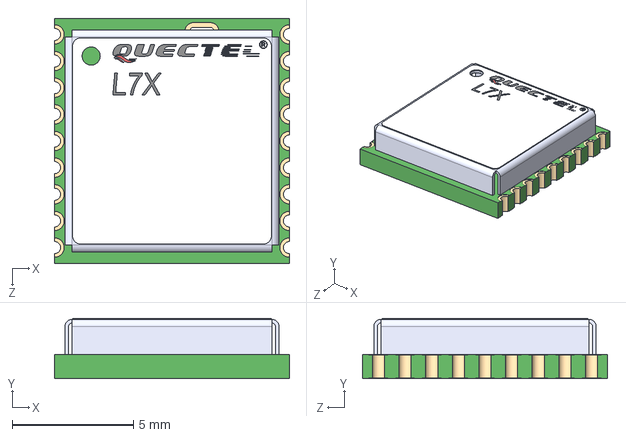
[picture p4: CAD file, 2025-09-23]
Breakout_Boards/L76LM33/V1/Symbols/L76L_M33/L76L-M33.step
9.70 x 2.49 x 10.1 mm

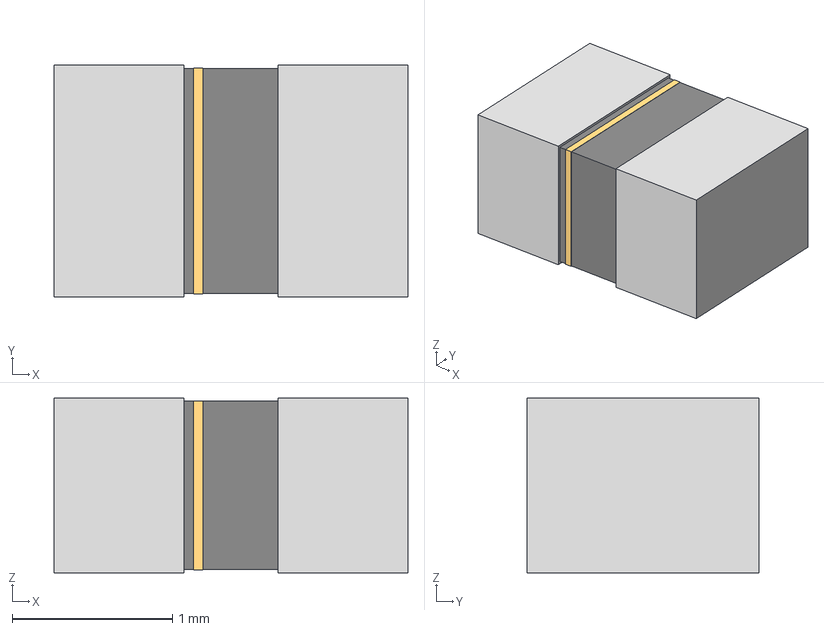
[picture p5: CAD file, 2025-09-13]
Breakout_Boards/ZED-F9P-15B/V1/Symbols/2508051217Y6/IND_25_0805_FRT.step
2.21 x 1.45 x 1.09 mm

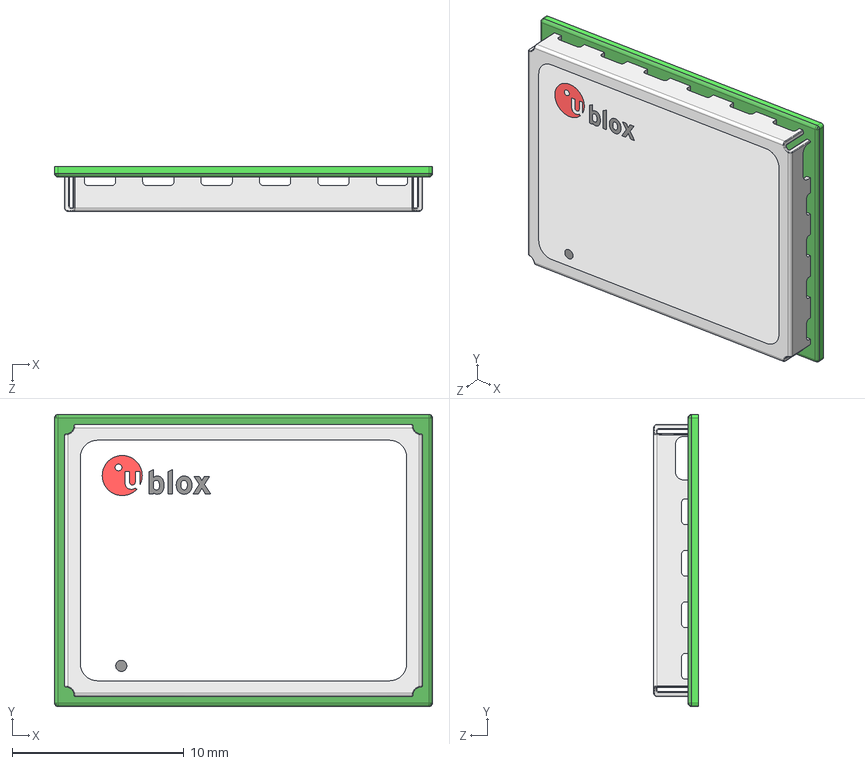
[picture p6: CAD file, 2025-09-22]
Breakout_Boards/ZED-F9P-15B/V1/Symbols/ZED-F9P-15B/ZED-F9P-15B.stp
22.0 x 17.0 x 2.60 mm
Ublox logo adjustable

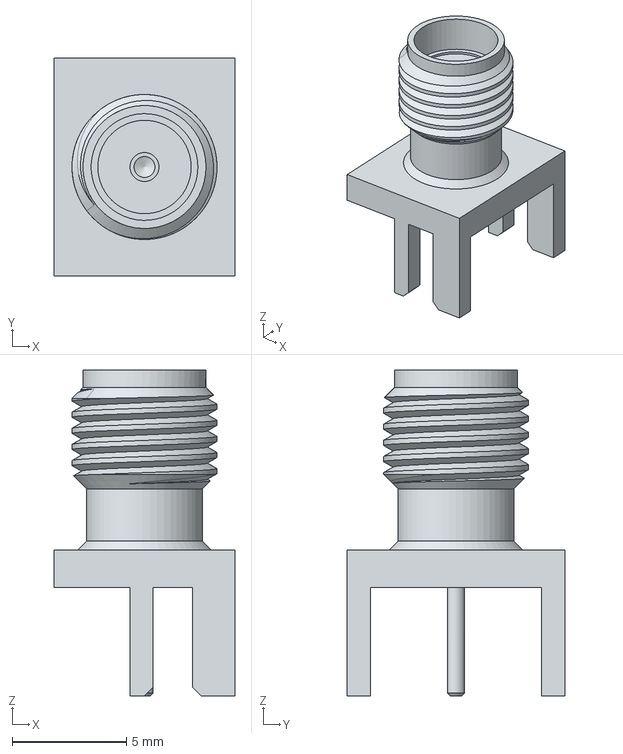
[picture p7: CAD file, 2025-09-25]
ODB_V3/Hardware/Kicad/Symbols/142_0701_801/142-0701-801.step
7.92 x 9.53 x 14.3 mm

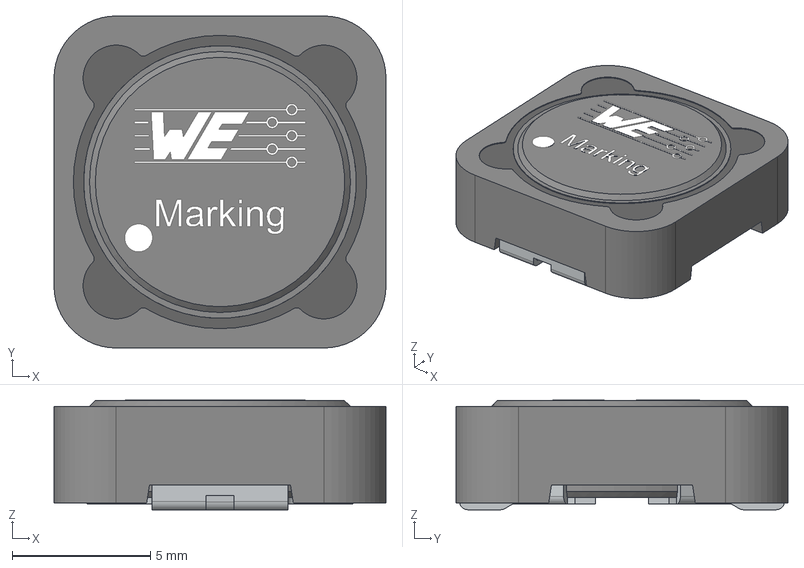
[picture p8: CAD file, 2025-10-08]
ODB_V3/Hardware/Kicad/Symbols/7447715330/WE-PD_1245.step
12.0 x 12.0 x 3.96 mm
Core
ShieldRing
Glue
Leadframe

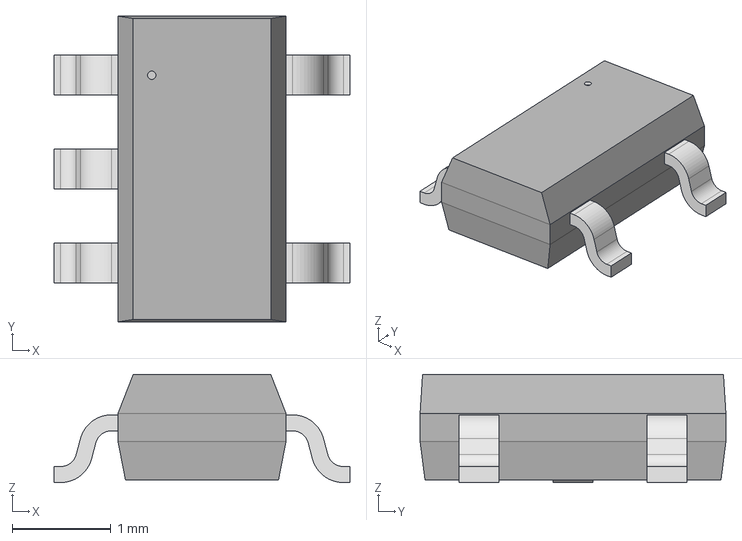
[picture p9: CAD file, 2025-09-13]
ODB_V3/Hardware/Kicad/Symbols/74LV1T87GVH/SC-74A_SOT753_NEX.step
3.00 x 3.10 x 1.09 mm

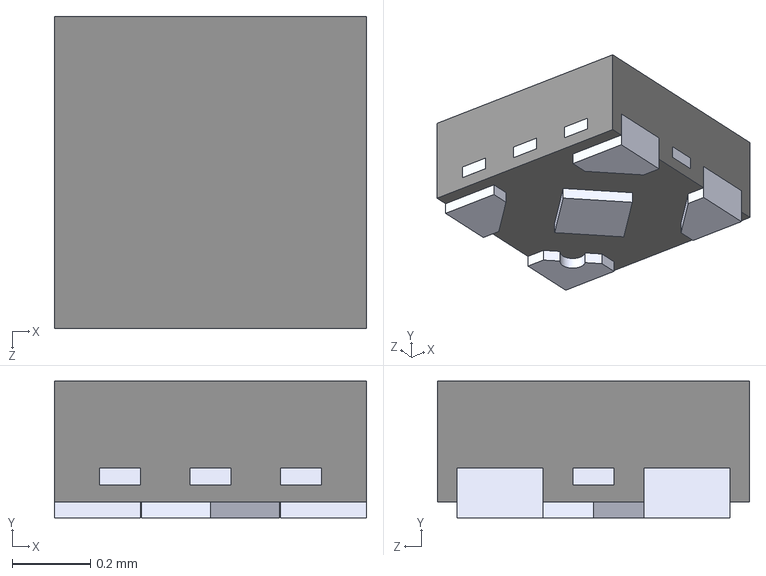
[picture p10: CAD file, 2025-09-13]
ODB_V3/Hardware/Kicad/Symbols/74LV1T87GXH/74LV1T87GXH.step
0.8 x 0.35 x 0.8 mm

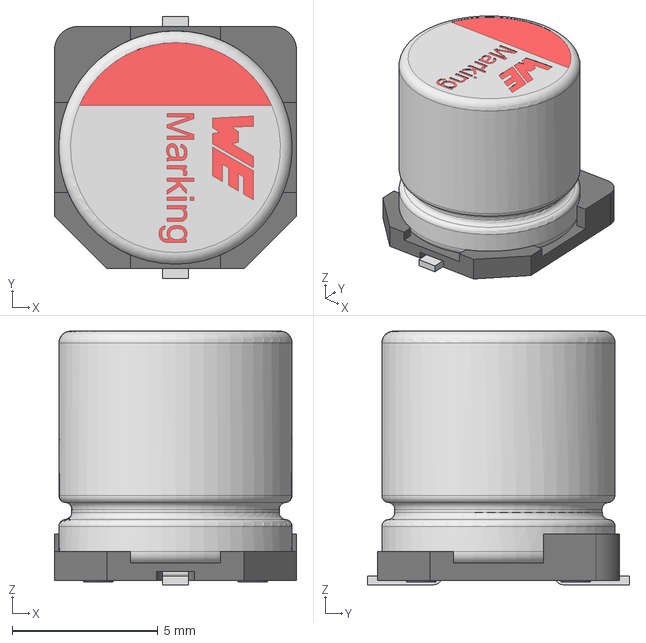
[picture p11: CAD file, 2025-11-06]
ODB_V3/Hardware/Kicad/Symbols/875115652007/Download_STP_875115xx20xx_rev1.stp
8.30 x 9.00 x 8.70 mm
Base_Φ8Capacitor
capicitor_8x8.7x3.1

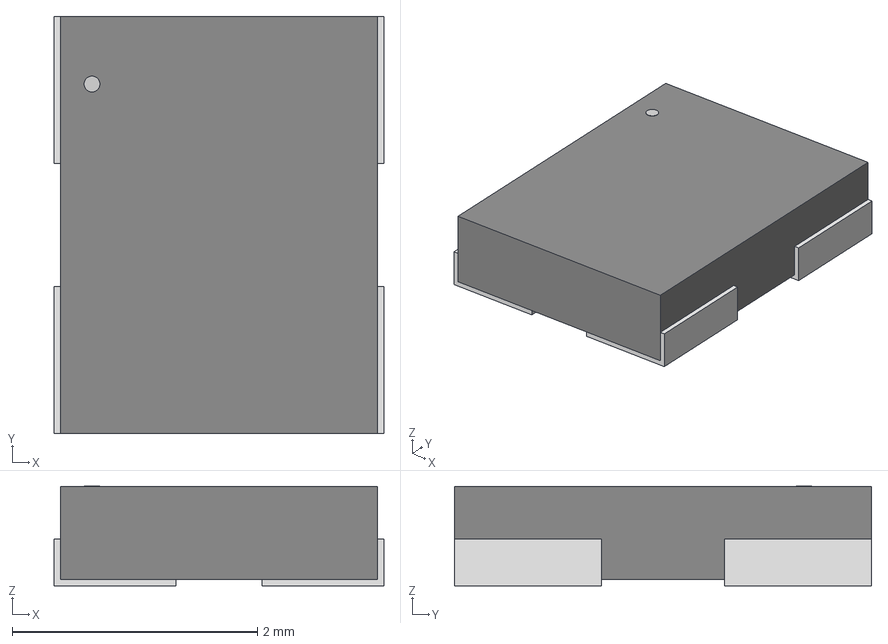
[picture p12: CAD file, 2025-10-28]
ODB_V3/Hardware/Kicad/Symbols/ABM8G_25_000MHZ_18_D2Y_T/CRYSTAL_ABM8G_ABR.step
2.69 x 3.40 x 0.815 mm

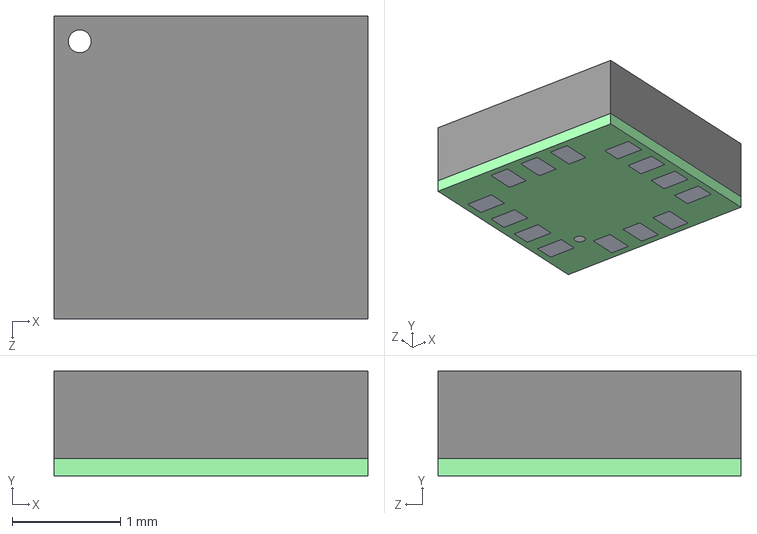
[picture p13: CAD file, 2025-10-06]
ODB_V3/Hardware/Kicad/Symbols/ADXL382_2BCCZ_RL7/ADXL382-2BCCZ-RL7.step
2.90 x 0.97 x 2.80 mm

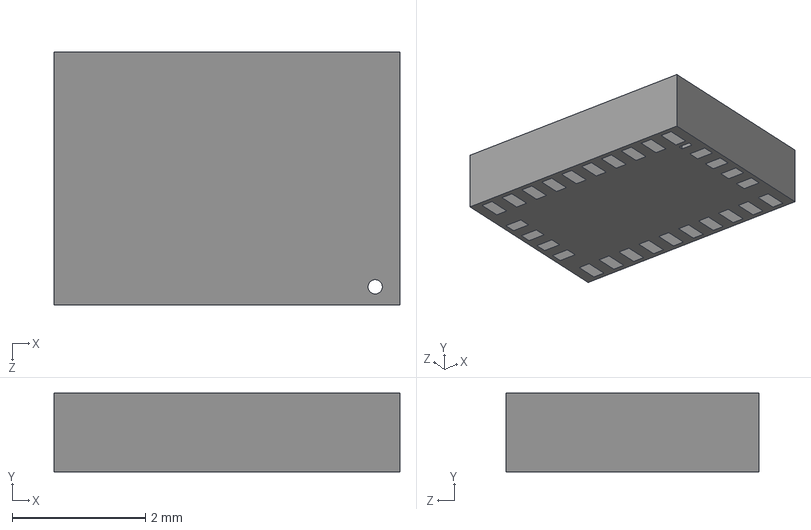
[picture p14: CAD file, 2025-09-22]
ODB_V3/Hardware/Kicad/Symbols/BNO055/BNO055.step
5.20 x 1.18 x 3.80 mm

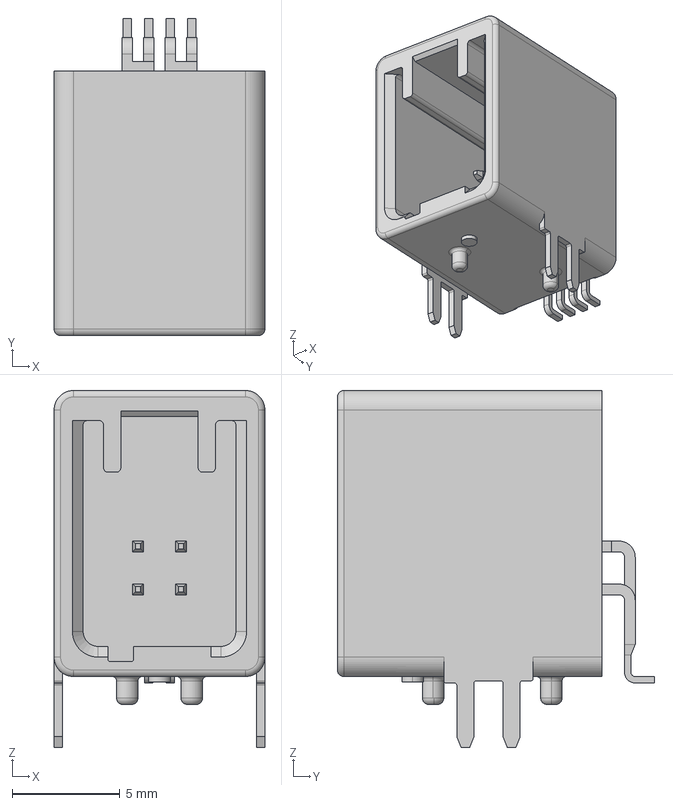
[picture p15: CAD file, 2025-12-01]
ODB_V3/Hardware/Kicad/Symbols/GT17HN_4DP_2H_A__56_/gt17hn-4dp-2h_a__56_.stp
9.80 x 14.8 x 16.6 mm

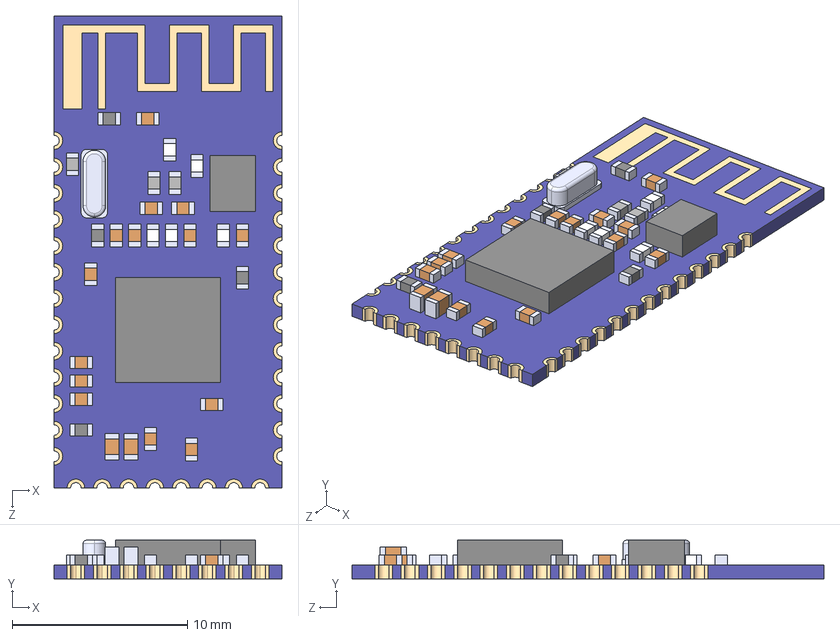
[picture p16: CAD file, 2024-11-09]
ODB_V3/Hardware/Kicad/Symbols/HM-10/HM-10.step
13.0 x 2.20 x 26.9 mm

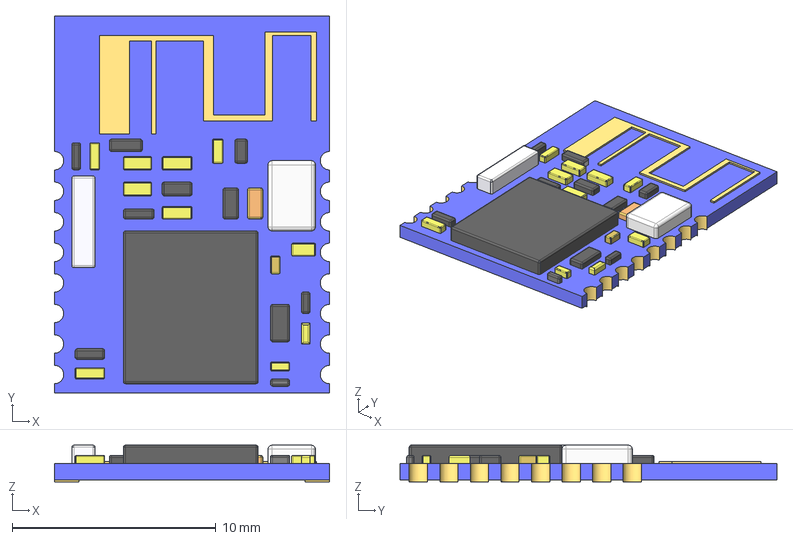
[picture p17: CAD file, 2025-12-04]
ODB_V3/Hardware/Kicad/Symbols/HM-11/HM11.stp
13.5 x 18.5 x 1.80 mm

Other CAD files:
ODB_V3/Hardware/Kicad/Symbols/ILSB0805ERR10K/IND_VISHAY_ILSB0805_A_VIS.step
ODB_V3/Hardware/Kicad/Symbols/IRFR5505TRPBF/IRFR5505TRPBF.STEP
ODB_V3/Hardware/Kicad/Symbols/L6981N33DR/L6981N33DR.step
ODB_V3/Hardware/Kicad/Symbols/LMT70YFQT/LMT70YFQT.step
ODB_V1/Hardware/Kicad/Symbols/ICM-20948/QFN24_3X3X0P9_IVS.step
ODB_V1/Hardware/Kicad/Symbols/JST_XA_B02B-XASK-1_1x02_P2.50mm_Vertical/B02B-XASK-1.step
ODB_V3/Hardware/Kicad/Symbols/1050170001/1050170001.stp
ODB_V3/Hardware/Kicad/Symbols/1715310000/1715310000.stp
ODB_V3/Hardware/Kicad/Symbols/282834_8/282834-8.step
ODB_V3/Hardware/Kicad/Symbols/2920L700_12MR/2920L700_12MR.stp
ODB_V3/Hardware/Kicad/Symbols/436500404/436500404.step
ODB_V3/Hardware/Kicad/Symbols/436500410/436500410.step
ODB_V3/Hardware/Kicad/Symbols/LQH3NPN3R3MMEL/LQH3NPN3R3MMEL.step
ODB_V3/Hardware/Kicad/Symbols/LTST-E682KRKGWT/LTST-E682KRKGWT.stp
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

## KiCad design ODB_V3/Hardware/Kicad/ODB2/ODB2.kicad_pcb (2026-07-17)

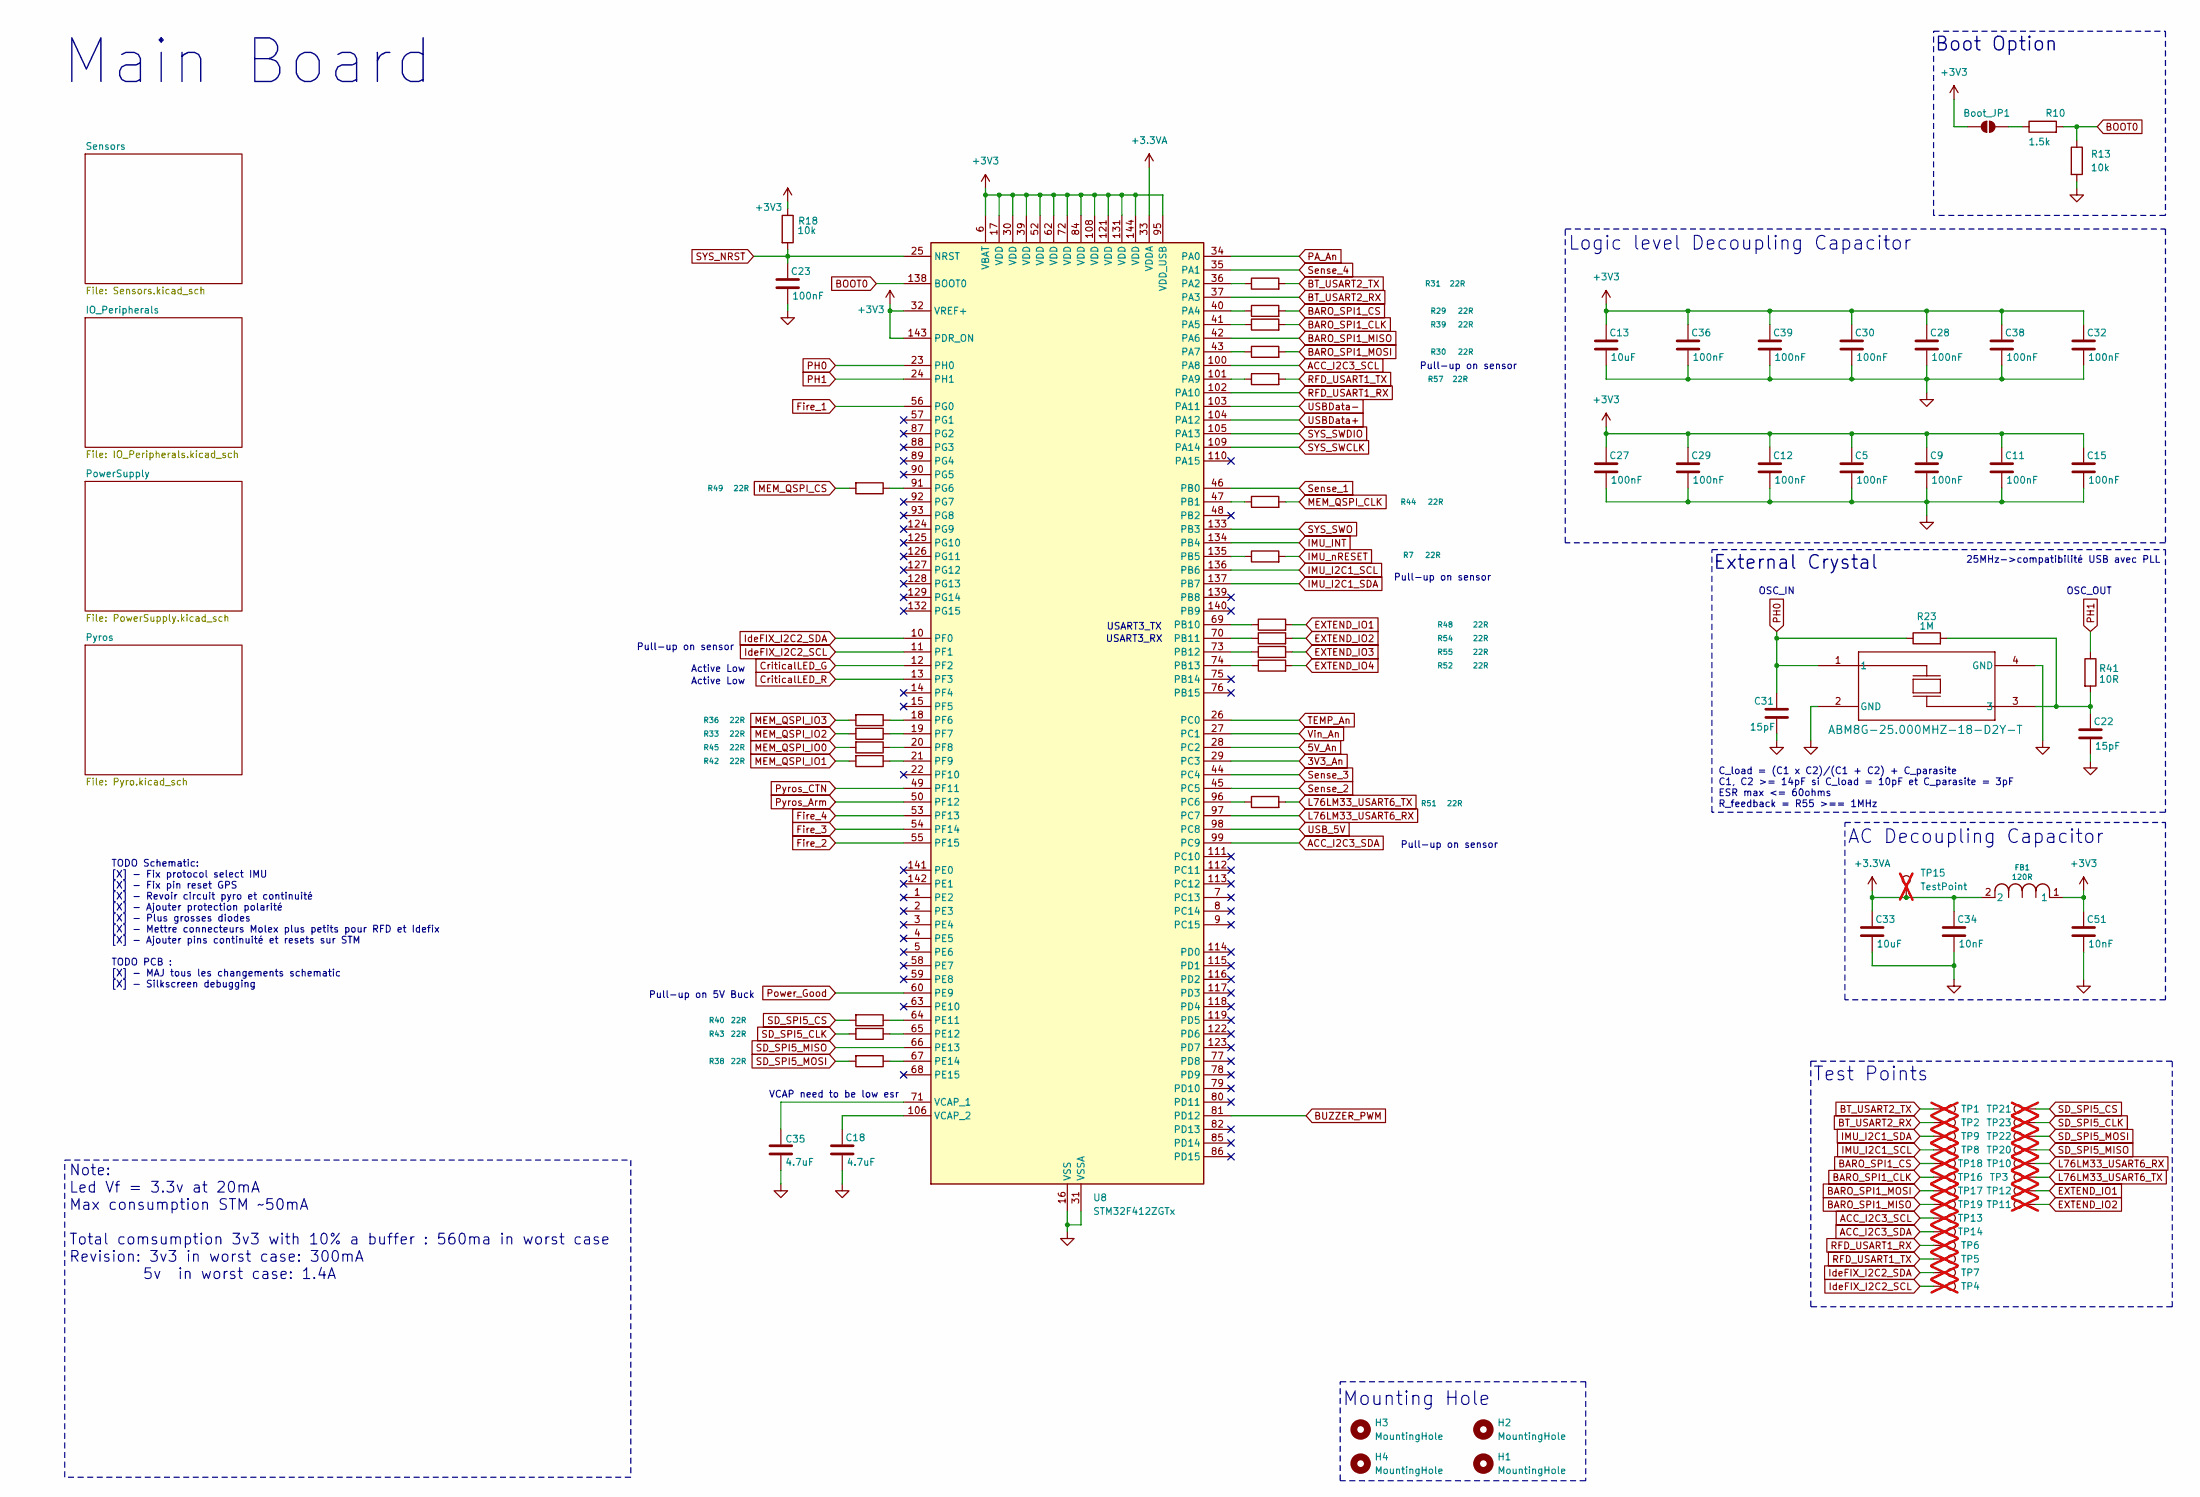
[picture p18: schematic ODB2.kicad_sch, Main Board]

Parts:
Boot_JP1: SolderJumper_2_Open; SolderJumper-2_P1.3mm_Open_TrianglePad1.0x1.5mm
C5, C9, C11, C12, C15, C23, C27, C28, C29, C30, C32, C36, C38, C39: 100nF; C_0402_1005Metric; Manufacturer_Part_Number CC0402KRX5R9BB104; DigiKey_Part_Number 311-3342-1-ND
C13, C33: 10uF; C_0603_1608Metric; Manufacturer_Part_Number GMC10X5R106M35NT; DigiKey_Part_Number 4713-GMC10X5R106M35NTTR-ND
C18, C35: 4.7uF; C_0603_1608Metric; Manufacturer_Part_Number NMC0603X5R475K6.3TRPF; DigiKey_Part_Number 4988-NMC0603X5R475K6.3TRPFCT-ND
C22, C31: 15pF; C_0402_1005Metric; Manufacturer_Part_Number GJM1555C1H150FB01D; DigiKey_Part_Number 490-11191-1-ND
C34, C51: 10nF; C_0402_1005Metric; Manufacturer_Part_Number GRM155R71C103KA01D; DigiKey_Part_Number 490-1313-1-ND
FB1: 120R; IND_25_0805_FRT; Manufacturer_Part_Number 2508051217Y6; DigiKey_Part_Number 1934-1472-1-ND
H1, H2, H3, H4: MountingHole; MountingHole_4.3mm_M4
R7, R29, R30, R31, R33, R36, R38, R39, R40, R42, R43, R44, R45, R48, R49, R51, R52, R54, R55, R57: 22R; R_0402_1005Metric; Manufacturer_Part_Number AC0402FR-0722RL; DigiKey_Part_Number YAG3460CT-ND
R10: 1.5k; R_0603_1608Metric; Manufacturer_Part_Number ERA-3AEB152V; DigiKey_Part_Number P1.5KDBCT-ND
R13, R18: 10k; R_0603_1608Metric; Manufacturer_Part_Number RC0603FR-0710KL; DigiKey_Part_Number 311-10.0KHRCT-ND
R23: 1M; R_0402_1005Metric; Manufacturer_Part_Number ERJ-2RKF1004X; DigiKey_Part_Number P1.00MLCT-ND
R41: 10R; R_0402_1005Metric; Manufacturer_Part_Number CRCW040210R0FKED; DigiKey_Part_Number 541-10.0LCT-ND
TP1, TP2, TP3, TP4, TP5, TP6, TP7, TP8, TP9, TP10, TP11, TP12, TP13, TP14, TP15, TP16, TP17, TP18, TP19, TP20, TP21, TP22, TP23: TestPoint; TestPoint_Pad_D1.0mm; not fitted
U8: STM32F412ZGTx; LQFP-144_20x20mm_P0.5mm; Manufacturer_Part_Number STM32F412ZGT6; DigiKey_Part_Number 497-16768-ND
Y1: ABM8G-25.000MHZ-18-D2Y-T; CRYSTAL_ABM8G_ABR; Manufacturer_Part_Number ABM8G-25.000MHZ-18-D2Y-T3; DigiKey_Part_Number 535-14129-1-ND

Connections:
3V3_An: U8.29 (PC3); also elsewhere on the board
3V3_Main: Boot_JP1.1 (A), C5.1, C9.1, C11.1, C12.1, C13.1, C15.1, C27.1, C28.1, C29.1, C30.1, C32.1, C36.1, C38.1, C39.1, C51.1, FB1.1, R18.1, U8.6 (VBAT), U8.17 (VDD), U8.30 (VDD), U8.32 (VREF+), U8.39 (VDD), U8.52 (VDD), U8.62 (VDD), U8.72 (VDD), U8.84 (VDD), U8.95 (VDD_USB), U8.108 (VDD), U8.121 (VDD), U8.131 (VDD), U8.143 (PDR_ON), U8.144 (VDD); also elsewhere on the board
5V_An: U8.28 (PC2); also elsewhere on the board
+3.3VA: C33.1, C34.1, FB1.2, TP15.1, U8.33 (VDDA)
ACC_I2C3_SCL: TP13.1 (1_1), U8.100 (PA8); also elsewhere on the board
ACC_I2C3_SDA: TP14.1 (1_1), U8.99 (PC9); also elsewhere on the board
BARO_SPI1_CLK: R39.2, TP16.1 (1_1); also elsewhere on the board
BARO_SPI1_CS: R29.2, TP18.1 (1_1); also elsewhere on the board
BARO_SPI1_MISO: TP19.1 (1_1), U8.42 (PA6); also elsewhere on the board
BARO_SPI1_MOSI: R30.2, TP17.1 (1_1); also elsewhere on the board
BOOT0: R10.2, R13.1, U8.138 (BOOT0)
BT_USART2_RX: TP2.1 (1_1), U8.37 (PA3); also elsewhere on the board
BT_USART2_TX: R31.2, TP1.1 (1_1); also elsewhere on the board
BUZZER_PWM: U8.81 (PD12); also elsewhere on the board
CriticalLED_G: U8.12 (PF2); also elsewhere on the board
CriticalLED_R: U8.13 (PF3); also elsewhere on the board
EXTEND_IO1: R48.2, TP12.1; also elsewhere on the board
EXTEND_IO2: R54.2, TP11.1; also elsewhere on the board
EXTEND_IO3: R55.2; also elsewhere on the board
EXTEND_IO4: R52.2; also elsewhere on the board
Fire_1: U8.56 (PG0); also elsewhere on the board
Fire_2: U8.55 (PF15); also elsewhere on the board
Fire_3: U8.54 (PF14); also elsewhere on the board
Fire_4: U8.53 (PF13); also elsewhere on the board
GND: C5.2, C9.2, C11.2, C12.2, C13.2, C15.2, C18.2, C22.2, C23.2, C27.2, C28.2, C29.2, C30.2, C31.2, C32.2, C33.2, C34.2, C35.2, C36.2, C38.2, C39.2, C51.2, R13.2, U8.16 (VSS), U8.31 (VSSA), U8.38 (VSS), U8.51 (VSS), U8.61 (VSS), U8.83 (VSS), U8.94 (VSS), U8.107 (VSS), U8.120 (VSS), U8.130 (VSS), Y1.2 (GND), Y1.4 (GND); also elsewhere on the board
IMU_I2C1_SCL: TP8.1 (1_1), U8.136 (PB6); also elsewhere on the board
IMU_I2C1_SDA: TP9.1 (1_1), U8.137 (PB7); also elsewhere on the board
IMU_INT: U8.134 (PB4); also elsewhere on the board
IMU_nRESET: R7.2; also elsewhere on the board
IdeFIX_I2C2_SCL: TP4.1 (1_1), U8.11 (PF1); also elsewhere on the board
IdeFIX_I2C2_SDA: TP7.1 (1_1), U8.10 (PF0); also elsewhere on the board
L76LM33_USART6_RX: TP10.1 (1_1), U8.97 (PC7); also elsewhere on the board
L76LM33_USART6_TX: R51.2, TP3.1 (1_1); also elsewhere on the board
MEM_QSPI_CLK: R44.2; also elsewhere on the board
MEM_QSPI_CS: R49.2; also elsewhere on the board
MEM_QSPI_IO0: R45.2; also elsewhere on the board
MEM_QSPI_IO1: R42.2; also elsewhere on the board
MEM_QSPI_IO2: R33.2; also elsewhere on the board
MEM_QSPI_IO3: R36.2; also elsewhere on the board
unnamed: Boot_JP1.2 (B), R10.1
unnamed: C22.1, R23.2, R41.2, Y1.3
unnamed: R31.1, U8.36 (PA2)
unnamed: R29.1, U8.40 (PA4)
unnamed: R39.1, U8.41 (PA5)
unnamed: R30.1, U8.43 (PA7)
unnamed: R57.1, U8.101 (PA9)
unnamed: R44.1, U8.47 (PB1)
unnamed: R7.1, U8.135 (PB5)
unnamed: R48.1, U8.69 (PB10)
unnamed: R54.1, U8.70 (PB11)
unnamed: R55.1, U8.73 (PB12)
unnamed: R52.1, U8.74 (PB13)
unnamed: R51.1, U8.96 (PC6)
unnamed: R40.1, U8.64 (PE11)
unnamed: R43.1, U8.65 (PE12)
unnamed: R38.1, U8.67 (PE14)
unnamed: R36.1, U8.18 (PF6)
unnamed: R33.1, U8.19 (PF7)
unnamed: R45.1, U8.20 (PF8)
unnamed: R42.1, U8.21 (PF9)
unnamed: R49.1, U8.91 (PG6)
unnamed: C35.1, U8.71 (VCAP_1)
unnamed: C18.1, U8.106 (VCAP_2)
PA_An: U8.34 (PA0); also elsewhere on the board
PH0: C31.1, R23.1, U8.23 (PH0), Y1.1
PH1: R41.1, U8.24 (PH1)
Power_Good: U8.60 (PE9); also elsewhere on the board
Pyros_Arm: U8.50 (PF12); also elsewhere on the board
Pyros_CTN: U8.49 (PF11); also elsewhere on the board
RFD_USART1_RX: TP6.1 (1_1), U8.102 (PA10); also elsewhere on the board
RFD_USART1_TX: R57.2, TP5.1 (1_1); also elsewhere on the board
SD_SPI5_CLK: R43.2, TP23.1 (1_1); also elsewhere on the board
SD_SPI5_CS: R40.2, TP21.1 (1_1); also elsewhere on the board
SD_SPI5_MISO: TP20.1 (1_1), U8.66 (PE13); also elsewhere on the board
SD_SPI5_MOSI: R38.2, TP22.1 (1_1); also elsewhere on the board
SYS_NRST: C23.1, R18.2, U8.25 (NRST); also elsewhere on the board
SYS_SWCLK: U8.109 (PA14); also elsewhere on the board
SYS_SWDIO: U8.105 (PA13); also elsewhere on the board
SYS_SWO: U8.133 (PB3); also elsewhere on the board
Sense_1: U8.46 (PB0); also elsewhere on the board
Sense_2: U8.45 (PC5); also elsewhere on the board
Sense_3: U8.44 (PC4); also elsewhere on the board
Sense_4: U8.35 (PA1); also elsewhere on the board
TEMP_An: U8.26 (PC0); also elsewhere on the board
USBData+: U8.104 (PA12); also elsewhere on the board
USBData-: U8.103 (PA11); also elsewhere on the board
USB_5V: U8.98 (PC8); also elsewhere on the board
Vin_An: U8.27 (PC1); also elsewhere on the board

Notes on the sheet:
VCAP need to be low esr
Pull-up on sensor
25MHz->compatibilité USB avec PLL
C_load = (C1 x C2)/(C1 + C2) + C_parasite C1, C2 >= 14pF si C_load = 10pF et C_parasite = 3pF ESR max <= 60ohms R_feedback = R55 >== 1MHz
Active Low
Pull-up on 5V Buck
Main Board
Mounting Hole
Boot Option
USART3_TX
Note: Led Vf = 3.3v at 20mA Max consumption STM ~50mA Total comsumption 3v3 with 10% a buffer : 560ma in worst case Revision: 3v3 in worst case: 300mA 5v in worst case: 1.4A
AC Decoupling Capacitor
OSC_OUT
Test Points
External Crystal
Logic level Decoupling Capacitor
OSC_IN
TODO Schematic: [X] - Fix protocol select IMU [X] - Fix pin reset GPS [X] - Revoir circuit pyro et continuité [X] - Ajouter protection polarité [X] - Plus grosses diodes [X] - Mettre connecteurs Molex plus petits pour RFD et Idefix [X] - Ajouter pins continuité et resets sur STM TODO PCB : [X] - MA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
USART3_RX

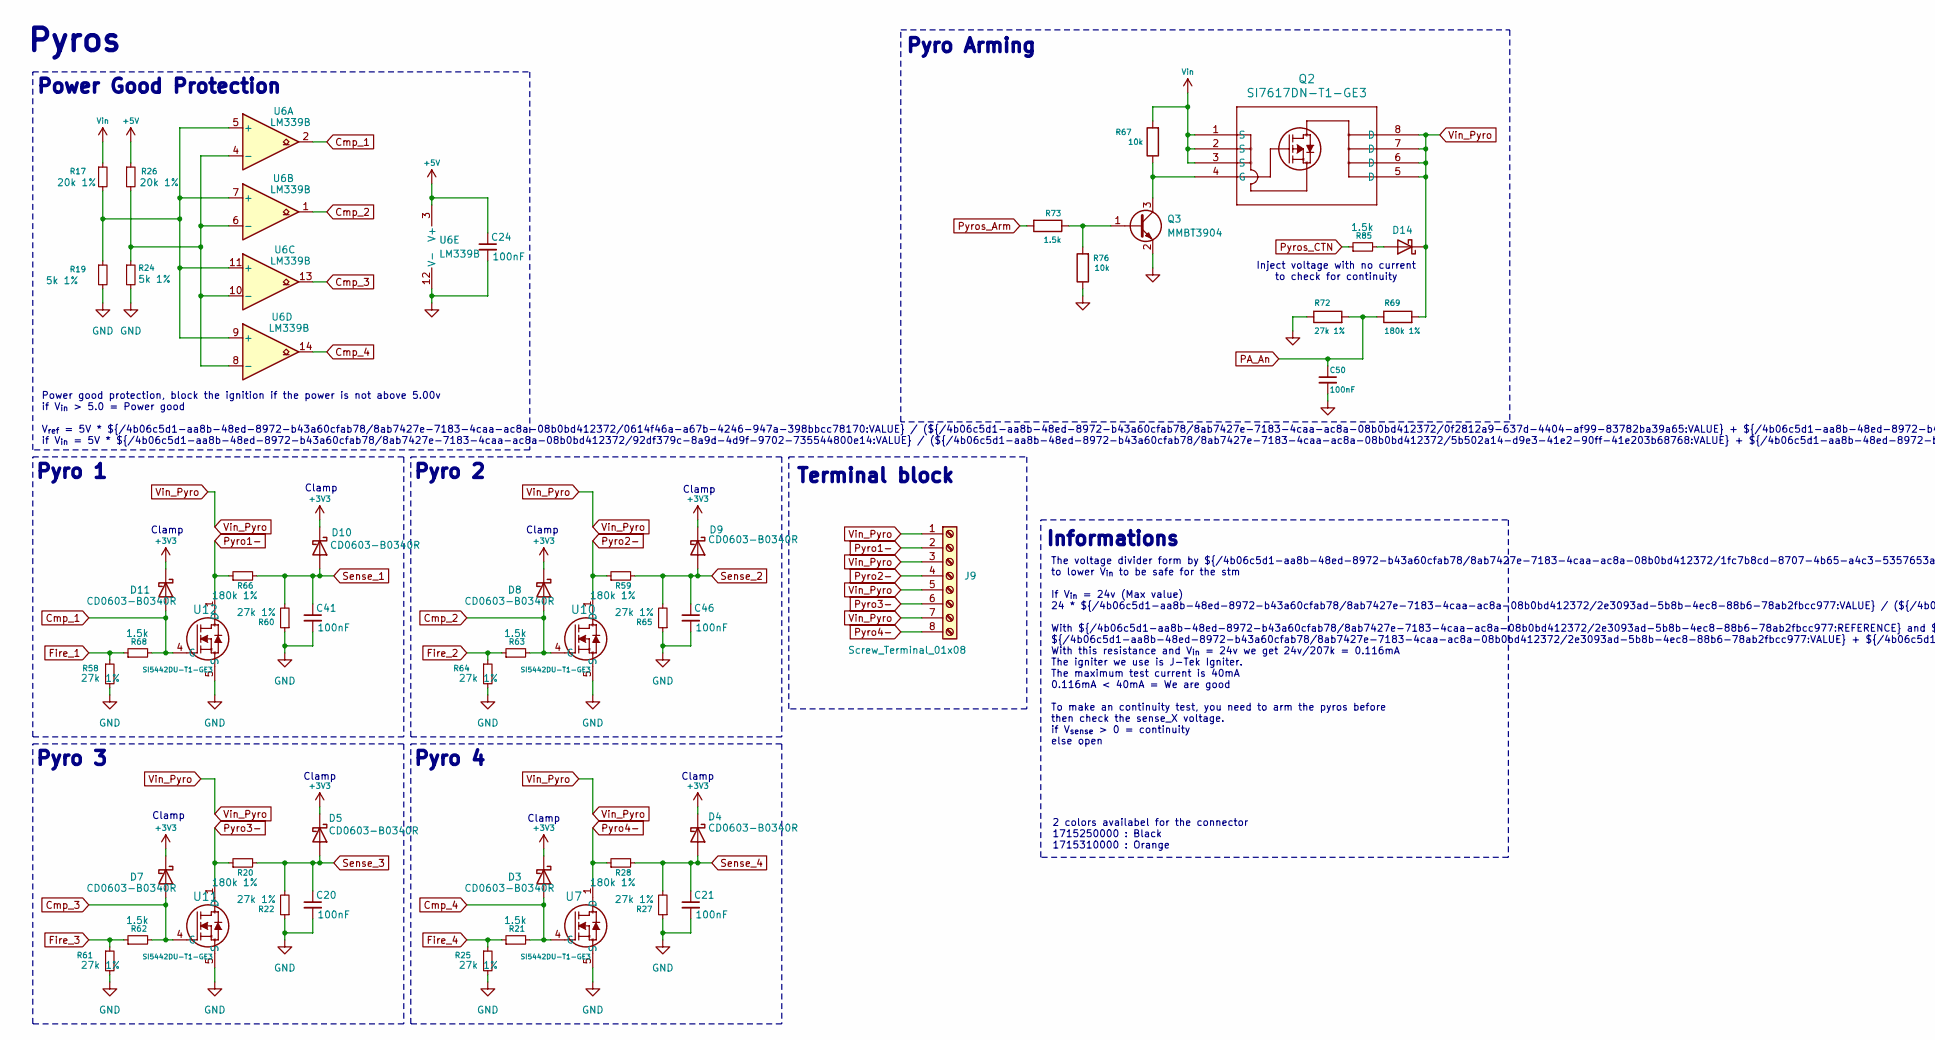
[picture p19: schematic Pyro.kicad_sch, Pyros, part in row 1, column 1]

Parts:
C20, C21, C24, C41, C46, C50: 100nF; C_0402_1005Metric; Manufacturer_Part_Number CC0402KRX5R9BB104; DigiKey_Part_Number 311-3342-1-ND
D3, D4, D5, D7, D8, D9, D10, D11, D14: CD0603-B0340R; D_0603_1608Metric; Manufacturer_Part_Number CD0603-B0340R; DigiKey_Part_Number CD0603-B0340RCT-ND
J9: Screw_Terminal_01x08; 8pin_terminal_2mm54; Manufacturer_Part_Number 1725711; DigiKey_Part_Number 277-1279-ND
Q2: SI7617DN-T1-GE3; POWERPAK_1212-8_VIS; Manufacturer_Part_Number SI7617DN-T1-GE3; DigiKey_Part_Number SI7617DN-T1-GE3CT-ND
Q3: MMBT3904; SOT-23; Manufacturer_Part_Number MMBT3904LT1G; DigiKey_Part_Number MMBT3904LT1GOSCT-ND
R17, R26: 20k 1%; R_0603_1608Metric; Manufacturer_Part_Number ERA-3AEB203V; DigiKey_Part_Number P20KDBCT-ND
R19, R24: 5k 1%; R_0603_1608Metric; Manufacturer_Part_Number MCT06030D5001BP500; DigiKey_Part_Number 541-MCT06030D5001BP500CT-ND
R20, R28, R59, R66, R69: 180k 1%; R_0603_1608Metric; Manufacturer_Part_Number ERA-3AEB184V; DigiKey_Part_Number P180KDBCT-ND
R21, R62, R63, R68, R73, R85: 1.5k; R_0603_1608Metric; Manufacturer_Part_Number ERA-3AEB152V; DigiKey_Part_Number P1.5KDBCT-ND
R22, R25, R27, R58, R60, R61, R64, R65, R72: 27k 1%; R_0603_1608Metric; Manufacturer_Part_Number RG1608P-273-B-T5; DigiKey_Part_Number RG16P27.0KBCT-ND
R67, R76: 10k; R_0603_1608Metric; Manufacturer_Part_Number RC0603FR-0710KL; DigiKey_Part_Number 311-10.0KHRCT-ND
U6: LM339B; TSSOP-14_4.4x5mm_P0.65mm; Manufacturer_Part_Number LM339BIPWR; DigiKey_Part_Number 296-LM339BIPWRCT-ND
U7, U10, U11, U12: SI5442DU-T1-GE3; SON_8DU-T1-GE3_VIS; Manufacturer_Part_Number SI5442DU-T1-GE3; DigiKey_Part_Number SI5442DU-T1-GE3CT-ND

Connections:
3V3_Main: D3.1 (K), D4.1 (K), D5.1 (K), D7.1 (K), D8.1 (K), D9.1 (K), D10.1 (K), D11.1 (K); also elsewhere on the board
5V_Main: C24.1, R26.1, U6.3 (V+); also elsewhere on the board
Cmp_1: D11.2 (A), R68.2, U6.2, U12.4 (G)
Cmp_2: D8.2 (A), R63.2, U6.1, U10.4 (G)
Cmp_3: D7.2 (A), R62.2, U6.13, U11.4 (G)
Cmp_4: D3.2 (A), R21.2, U6.14, U7.4 (G)
Fire_1: R58.1, R68.1; also elsewhere on the board
Fire_2: R63.1, R64.1; also elsewhere on the board
Fire_3: R61.1, R62.1; also elsewhere on the board
Fire_4: R21.1, R25.1; also elsewhere on the board
GND: C20.2, C21.2, C24.2, C41.2, C46.2, C50.2, Q3.2 (E), R19.2, R22.1, R24.2, R25.2, R27.1, R58.2, R60.1, R61.2, R64.2, R65.1, R72.1, R76.1, U6.12 (V-), U7.5 (S), U7.9 (S), U10.5 (S), U10.9 (S), U11.5 (S), U11.9 (S), U12.5 (S), U12.9 (S); also elsewhere on the board
unnamed: D14.2 (A), R85.2
unnamed: Q2.4 (G), Q3.3 (C), R67.1
unnamed: Q3.1 (B), R73.1, R76.2
unnamed: R17.2, R19.1, U6.5 (+), U6.7 (+), U6.9 (+), U6.11 (+)
unnamed: R24.1, R26.2, U6.4 (-), U6.6 (-), U6.8 (-), U6.10 (-)
PA_An: C50.1, R69.1, R72.2; also elsewhere on the board
Pyro1-: J9.2, R66.1, U12.1 (D), U12.2 (D), U12.3 (D), U12.6 (D), U12.7 (D), U12.8 (D), U12.10 (D)
Pyro2-: J9.4, R59.1, U10.1 (D), U10.2 (D), U10.3 (D), U10.6 (D), U10.7 (D), U10.8 (D), U10.10 (D)
Pyro3-: J9.6, R20.1, U11.1 (D), U11.2 (D), U11.3 (D), U11.6 (D), U11.7 (D), U11.8 (D), U11.10 (D)
Pyro4-: J9.8, R28.1, U7.1 (D), U7.2 (D), U7.3 (D), U7.6 (D), U7.7 (D), U7.8 (D), U7.10 (D)
Pyros_Arm: R73.2; also elsewhere on the board
Pyros_CTN: R85.1; also elsewhere on the board
Sense_1: C41.1, D10.2 (A), R60.2, R66.2; also elsewhere on the board
Sense_2: C46.1, D9.2 (A), R59.2, R65.2; also elsewhere on the board
Sense_3: C20.1, D5.2 (A), R20.2, R22.2; also elsewhere on the board
Sense_4: C21.1, D4.2 (A), R27.2, R28.2; also elsewhere on the board
VIN_Filtered: Q2.1 (S), Q2.2 (S), Q2.3 (S), R17.1, R67.2; also elsewhere on the board
Vin_Pyro: D14.1 (K), J9.1, J9.3, J9.5, J9.7, Q2.5 (D), Q2.6 (D), Q2.7 (D), Q2.8 (D), Q2.9 (D), R69.2

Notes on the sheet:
Pyro Arming
Clamp
Pyro 1
Pyros
Power good protection, block the ignition if the power is not above 5.00v if V_{in} > 5.0 = Power good V_{ref} = 5V * ${/4b06c5d1-aa8b-48ed-8972-b43a60cfab78/8ab7427e-7183-4caa-ac8a-08b0bd412372/0614f46a-a67b-4246-947a-398bbcc78170:VALUE} / (${/4b06c5d1-aa8b-48ed-8972-b43a60cfab78/8ab7427e-7183-4ca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
Pyro 4
Pyro 2
2 colors availabel for the connector 1715250000 : Black 1715310000 : Orange
The voltage divider form by ${/4b06c5d1-aa8b-48ed-8972-b43a60cfab78/8ab7427e-7183-4caa-ac8a-08b0bd412372/1fc7b8cd-8707-4b65-a4c3-5357653aeaad:REFERENCE} and ${/4b06c5d1-aa8b-48ed-8972-b43a60cfab78/8ab7427e-7183-4caa-ac8a-08b0bd412372/2e3093ad-5b8b-4ec8-88b6-78ab2fbcc977:REFERENCE} are there to lowe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
Power Good Protection
Inject voltage with no current to check for continuity
Terminal block
Informations
Pyro 3

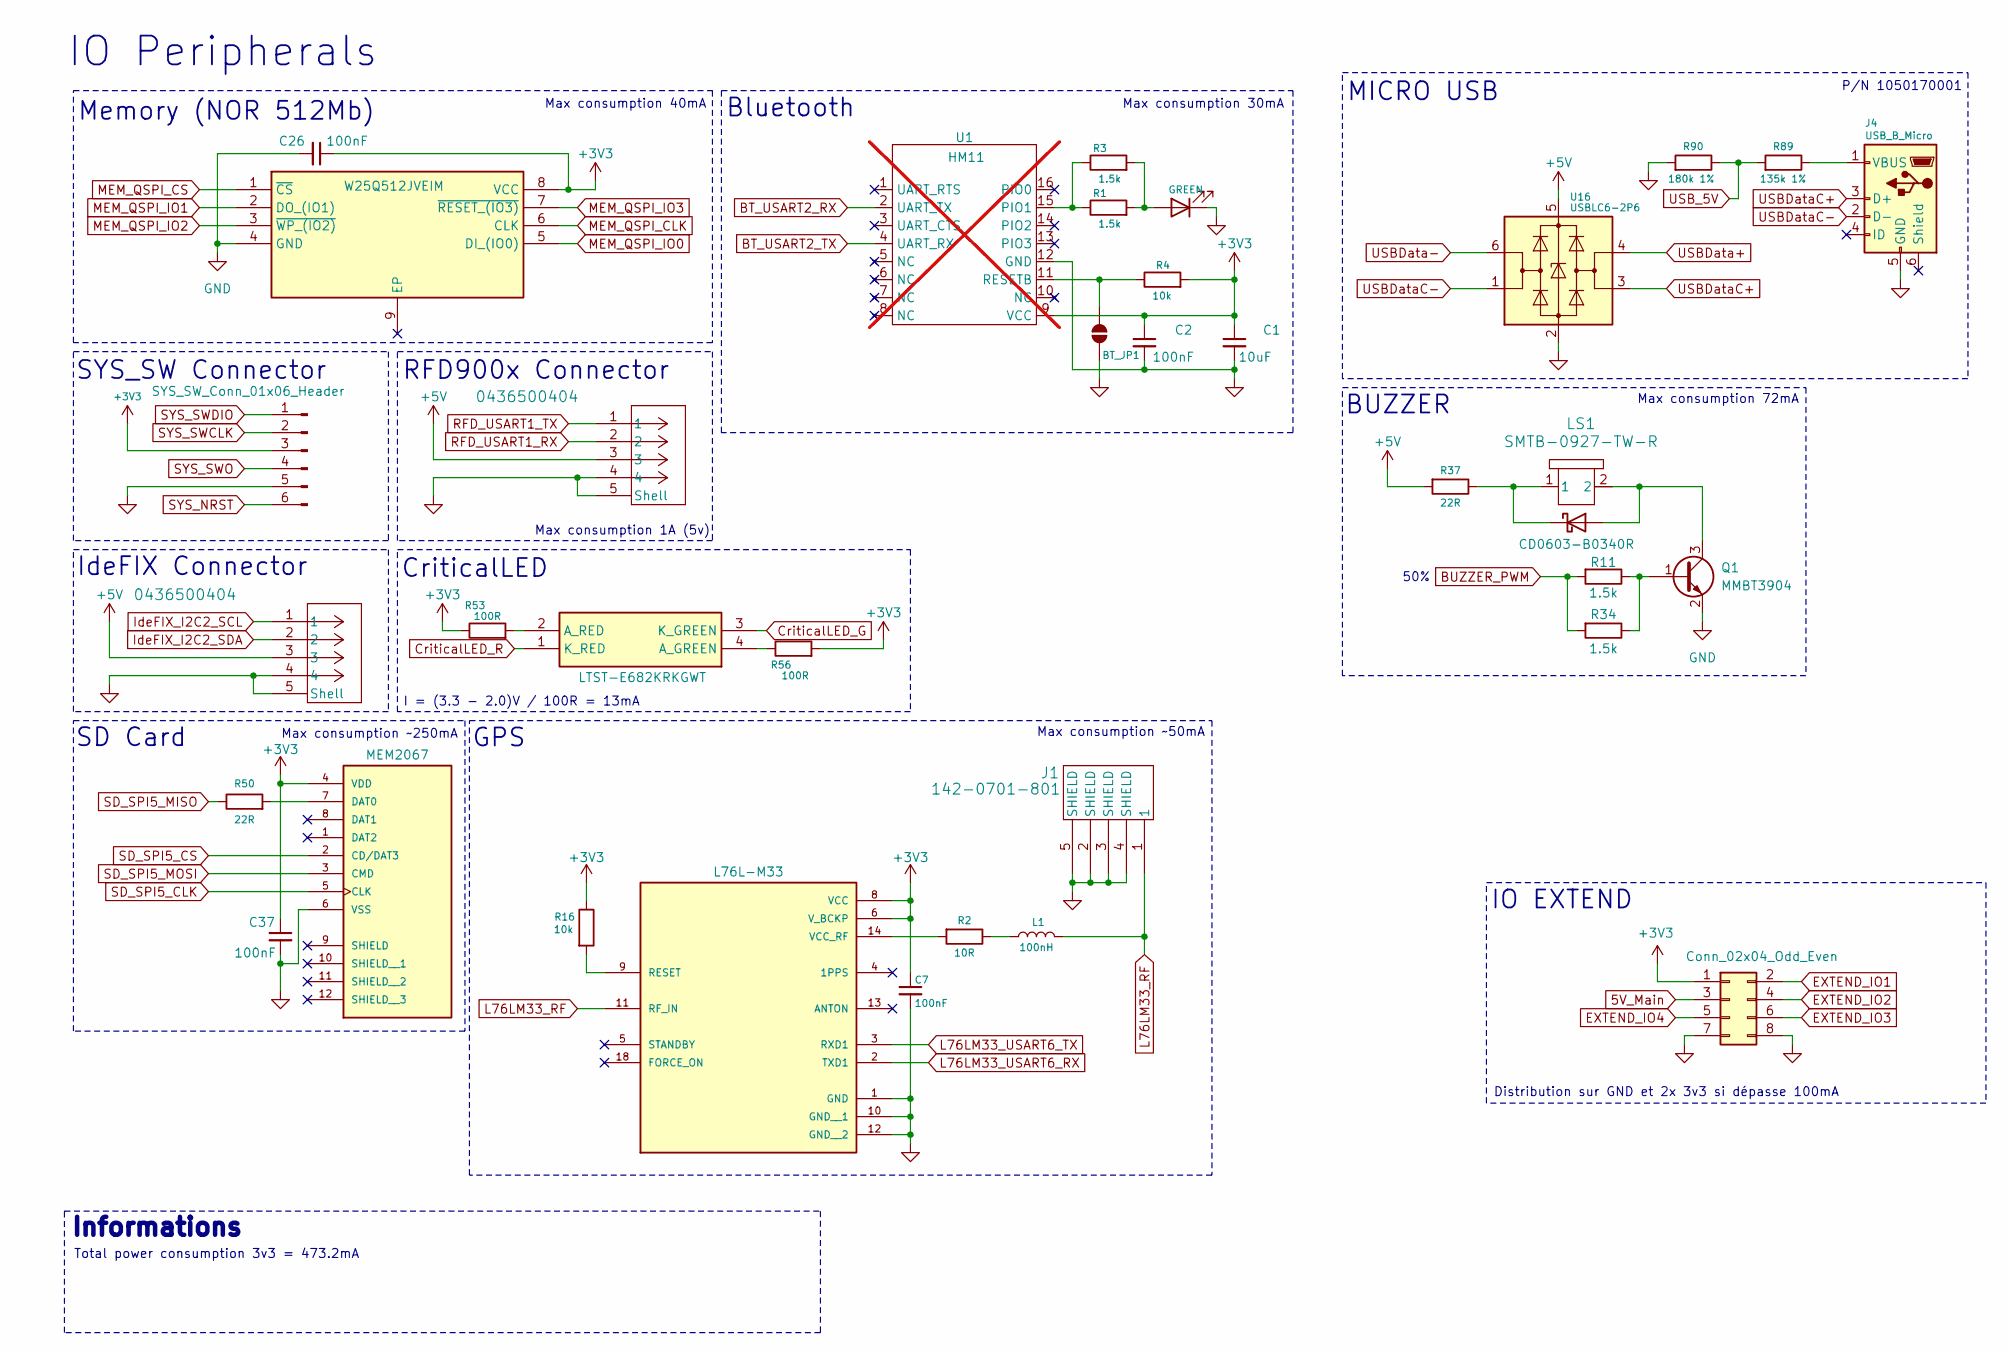
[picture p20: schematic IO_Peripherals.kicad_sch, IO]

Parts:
BT_JP1: SolderJumper_2_Open; SolderJumper-2_P1.3mm_Open_TrianglePad1.0x1.5mm
C1: 10uF; C_0603_1608Metric; Manufacturer_Part_Number GMC10X5R106M35NT; DigiKey_Part_Number 4713-GMC10X5R106M35NTTR-ND
C2, C7, C26, C37: 100nF; C_0402_1005Metric; Manufacturer_Part_Number CC0402KRX5R9BB104; DigiKey_Part_Number 311-3342-1-ND
D1: GREEN; LED_QBLP601-AG15; Manufacturer_Part_Number QBLP601-AG15; DigiKey_Part_Number 1516-QBLP601-AG15CT-ND
D2: CD0603-B0340R; D_0603_1608Metric; Manufacturer_Part_Number CD0603-B0340R; DigiKey_Part_Number CD0603-B0340RCT-ND
D6: LTST-E682KRKGWT; LTSTE683RGBW; Mouser Part Number 859-LTST-E682KRKGWT
J1: 142-0701-801; CONN_142-0701-801; Manufacturer_Part_Number 142-0701-801; DigiKey_Part_Number J502-ND
J2, J3: 0436500404; CONN_SD-43650-002_04_MOL; Manufacturer_Part_Number 0436500404; DigiKey_Part_Number WM1877-ND
J4: USB_B_Micro; USB_Micro-B_Molex-105017-0001; Manufacturer_Part_Number 1050170001; DigiKey_Part_Number WM1399CT-ND
J5: SYS_SW_Conn_01x06_Header; PinHeader_1x06_P2.54mm_Vertical; Manufacturer_Part_Number 61300611121; DigiKey_Part_Number 732-5319-ND
J7: Conn_02x04_Odd_Even; PinHeader_2x04_P2.54mm_Vertical; Manufacturer_Part_Number 61300821121; DigiKey_Part_Number 732-5296-ND
J10: MEM2067; GCT_MEM2067-02-180-00-A_REVB; Manufacturer_Part_Number MEM2067-02-180-00-A; DigiKey_Part_Number 2073-MEM2067-02-180-00-ACT-ND
L1: 100nH; L_0603_1608Metric; Manufacturer_Part_Number AIML-0603-R10K-T; DigiKey_Part_Number 535-11609-1-ND
LS1: SMTB-0927-TW-R; SMTB-0927-TW-R_PUI; Manufacturer_Part_Number SMTB-0927-TW-R; DigiKey_Part_Number 668-SMTB-0927-TW-RCT-ND
Q1: MMBT3904; SOT-23; Manufacturer_Part_Number MMBT3904LT1G; DigiKey_Part_Number MMBT3904LT1GOSCT-ND
R1, R3, R11, R34: 1.5k; R_0603_1608Metric; Manufacturer_Part_Number ERA-3AEB152V; DigiKey_Part_Number P1.5KDBCT-ND
R2: 10R; R_0402_1005Metric; Manufacturer_Part_Number CRCW040210R0FKED; DigiKey_Part_Number 541-10.0LCT-ND
R4, R16: 10k; R_0603_1608Metric; Manufacturer_Part_Number RC0603FR-0710KL; DigiKey_Part_Number 311-10.0KHRCT-ND
R37: 22R; R_0402_1005Metric; Manufacturer_Part_Number 2019-SG73P1EWTTP22R0FTR-ND; DigiKey_Part_Number SG73P1EWTTP22R0F
R50: 22R; R_0402_1005Metric; Manufacturer_Part_Number AC0402FR-0722RL; DigiKey_Part_Number YAG3460CT-ND
R53, R56: 100R; R_0603_1608Metric; Manufacturer_Part_Number PCAN0603E1000BST5; DigiKey_Part_Number 764-1252-1-ND
R89: 135k 1%; R_0603_1608Metric; Manufacturer_Part_Number RT0603BRD07135KL; DigiKey_Part_Number 13-RT0603BRD07135KLCT-ND
R90: 180k 1%; R_0603_1608Metric; Manufacturer_Part_Number ERA-3AEB184V; DigiKey_Part_Number P180KDBCT-ND
U1: HM11; hm11; not fitted
U2: L76L-M33; Quectel_L76; Manufacturer_Part_Number L76L-M33; DigiKey_Part_Number 2958-L76L-M33CT-ND
U9: W25Q512JVEIM; SON127P800X600X80-9N-D; Mouser Part Number 454-W25Q512JVEIQ
U16: USBLC6-2P6; SOT-666; Manufacturer_Part_Number USBLC6-2P6; DigiKey_Part_Number 497-5026-1-ND

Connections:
3V3_Main: C1.1, C2.1, C7.1, C26.1, C37.1, J5.3, J7.1, J10.4 (VDD), R4.2, R16.1, R53.1, R56.2, U1.9 (VCC), U2.6 (V_BCKP), U2.8 (VCC), U9.8 (VCC); also elsewhere on the board
5V_Main: J2.3, J3.3, J7.3, R37.2, U16.5 (VBUS); also elsewhere on the board
BT_USART2_RX: U1.2 (UART_TX); also elsewhere on the board
BT_USART2_TX: U1.4 (UART_RX); also elsewhere on the board
BUZZER_PWM: R11.2, R34.2; also elsewhere on the board
CriticalLED_G: D6.3 (K_GREEN); also elsewhere on the board
CriticalLED_R: D6.1 (K_RED); also elsewhere on the board
EXTEND_IO1: J7.2; also elsewhere on the board
EXTEND_IO2: J7.4; also elsewhere on the board
EXTEND_IO3: J7.6; also elsewhere on the board
EXTEND_IO4: J7.5; also elsewhere on the board
GND: BT_JP1.1 (A), C1.2, C2.2, C7.2, C26.2, C37.2, D1.1 (K), J1.2 (SHIELD), J1.3 (SHIELD), J1.4 (SHIELD), J1.5 (SHIELD), J2.4, J2.5 (Shell), J2.6 (Shell), J2.7 (Shell), J2.8 (Shell), J3.4, J3.5 (Shell), J3.6 (Shell), J3.7 (Shell), J3.8 (Shell), J4.5 (GND), J5.5, J7.7, J7.8, J10.6 (VSS), Q1.2 (E), R90.2, U1.12 (GND), U2.1 (GND), U2.10 (GND__1), U2.12 (GND__2), U9.4 (GND), U16.2 (GND); also elsewhere on the board
IdeFIX_I2C2_SCL: J2.1; also elsewhere on the board
IdeFIX_I2C2_SDA: J2.2; also elsewhere on the board
L76LM33_RF: J1.1, L1.2, U2.11 (RF_IN)
L76LM33_USART6_RX: U2.2 (TXD1); also elsewhere on the board
L76LM33_USART6_TX: U2.3 (RXD1); also elsewhere on the board
MEM_QSPI_CLK: U9.6 (CLK); also elsewhere on the board
MEM_QSPI_CS: U9.1 (~CS); also elsewhere on the board
MEM_QSPI_IO0: U9.5 (DI_(IO0)); also elsewhere on the board
MEM_QSPI_IO1: U9.2 (DO_(IO1)); also elsewhere on the board
MEM_QSPI_IO2: U9.3 (~WP_(IO2)); also elsewhere on the board
MEM_QSPI_IO3: U9.7 (~RESET_(IO3)); also elsewhere on the board
unnamed: BT_JP1.2 (B), R4.1, U1.11 (RESETB)
unnamed: D1.2 (A), R1.2, R3.2
unnamed: D2.2 (A), LS1.2, Q1.3 (C)
unnamed: D2.1 (K), LS1.1, R37.1
unnamed: D6.4 (A_GREEN), R56.1
unnamed: D6.2 (A_RED), R53.2
unnamed: J4.1 (VBUS), R89.1
unnamed: J10.7 (DAT0), R50.2
unnamed: L1.1, R2.1
unnamed: Q1.1 (B), R11.1, R34.1
unnamed: R1.1, R3.1, U1.15 (PIO1)
unnamed: R16.2, U2.9 (RESET)
unnamed: R2.2, U2.14 (VCC_RF)
RFD_USART1_RX: J3.2; also elsewhere on the board
RFD_USART1_TX: J3.1; also elsewhere on the board
SD_SPI5_CLK: J10.5 (CLK); also elsewhere on the board
SD_SPI5_CS: J10.2 (CD/DAT3); also elsewhere on the board
SD_SPI5_MISO: R50.1; also elsewhere on the board
SD_SPI5_MOSI: J10.3 (CMD); also elsewhere on the board
SYS_NRST: J5.6; also elsewhere on the board
SYS_SWCLK: J5.2; also elsewhere on the board
SYS_SWDIO: J5.1; also elsewhere on the board
SYS_SWO: J5.4; also elsewhere on the board
USBData+: U16.4 (I/O2); also elsewhere on the board
USBData-: U16.6 (I/O1); also elsewhere on the board
USBDataC+: J4.3 (D+), U16.3 (I/O2)
USBDataC-: J4.2 (D-), U16.1 (I/O1)
USB_5V: R89.2, R90.1; also elsewhere on the board

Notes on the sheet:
IO EXTEND
Max consumption 72mA
Max consumption ~250mA
IO Peripherals
Bluetooth
GPS
SD Card
Memory (NOR 512Mb)
Total power consumption 3v3 = 473.2mA
50%
IdeFIX Connector
Max consumption 40mA
Max consumption ~50mA
Informations
Max consumption 1A (5v)
CriticalLED
MICRO USB
P/N 1050170001
I = (3.3 - 2.0)V / 100R = 13mA
BUZZER
Max consumption 30mA
Distribution sur GND et 2x 3v3 si dépasse 100mA
RFD900x Connector
SYS_SW Connector

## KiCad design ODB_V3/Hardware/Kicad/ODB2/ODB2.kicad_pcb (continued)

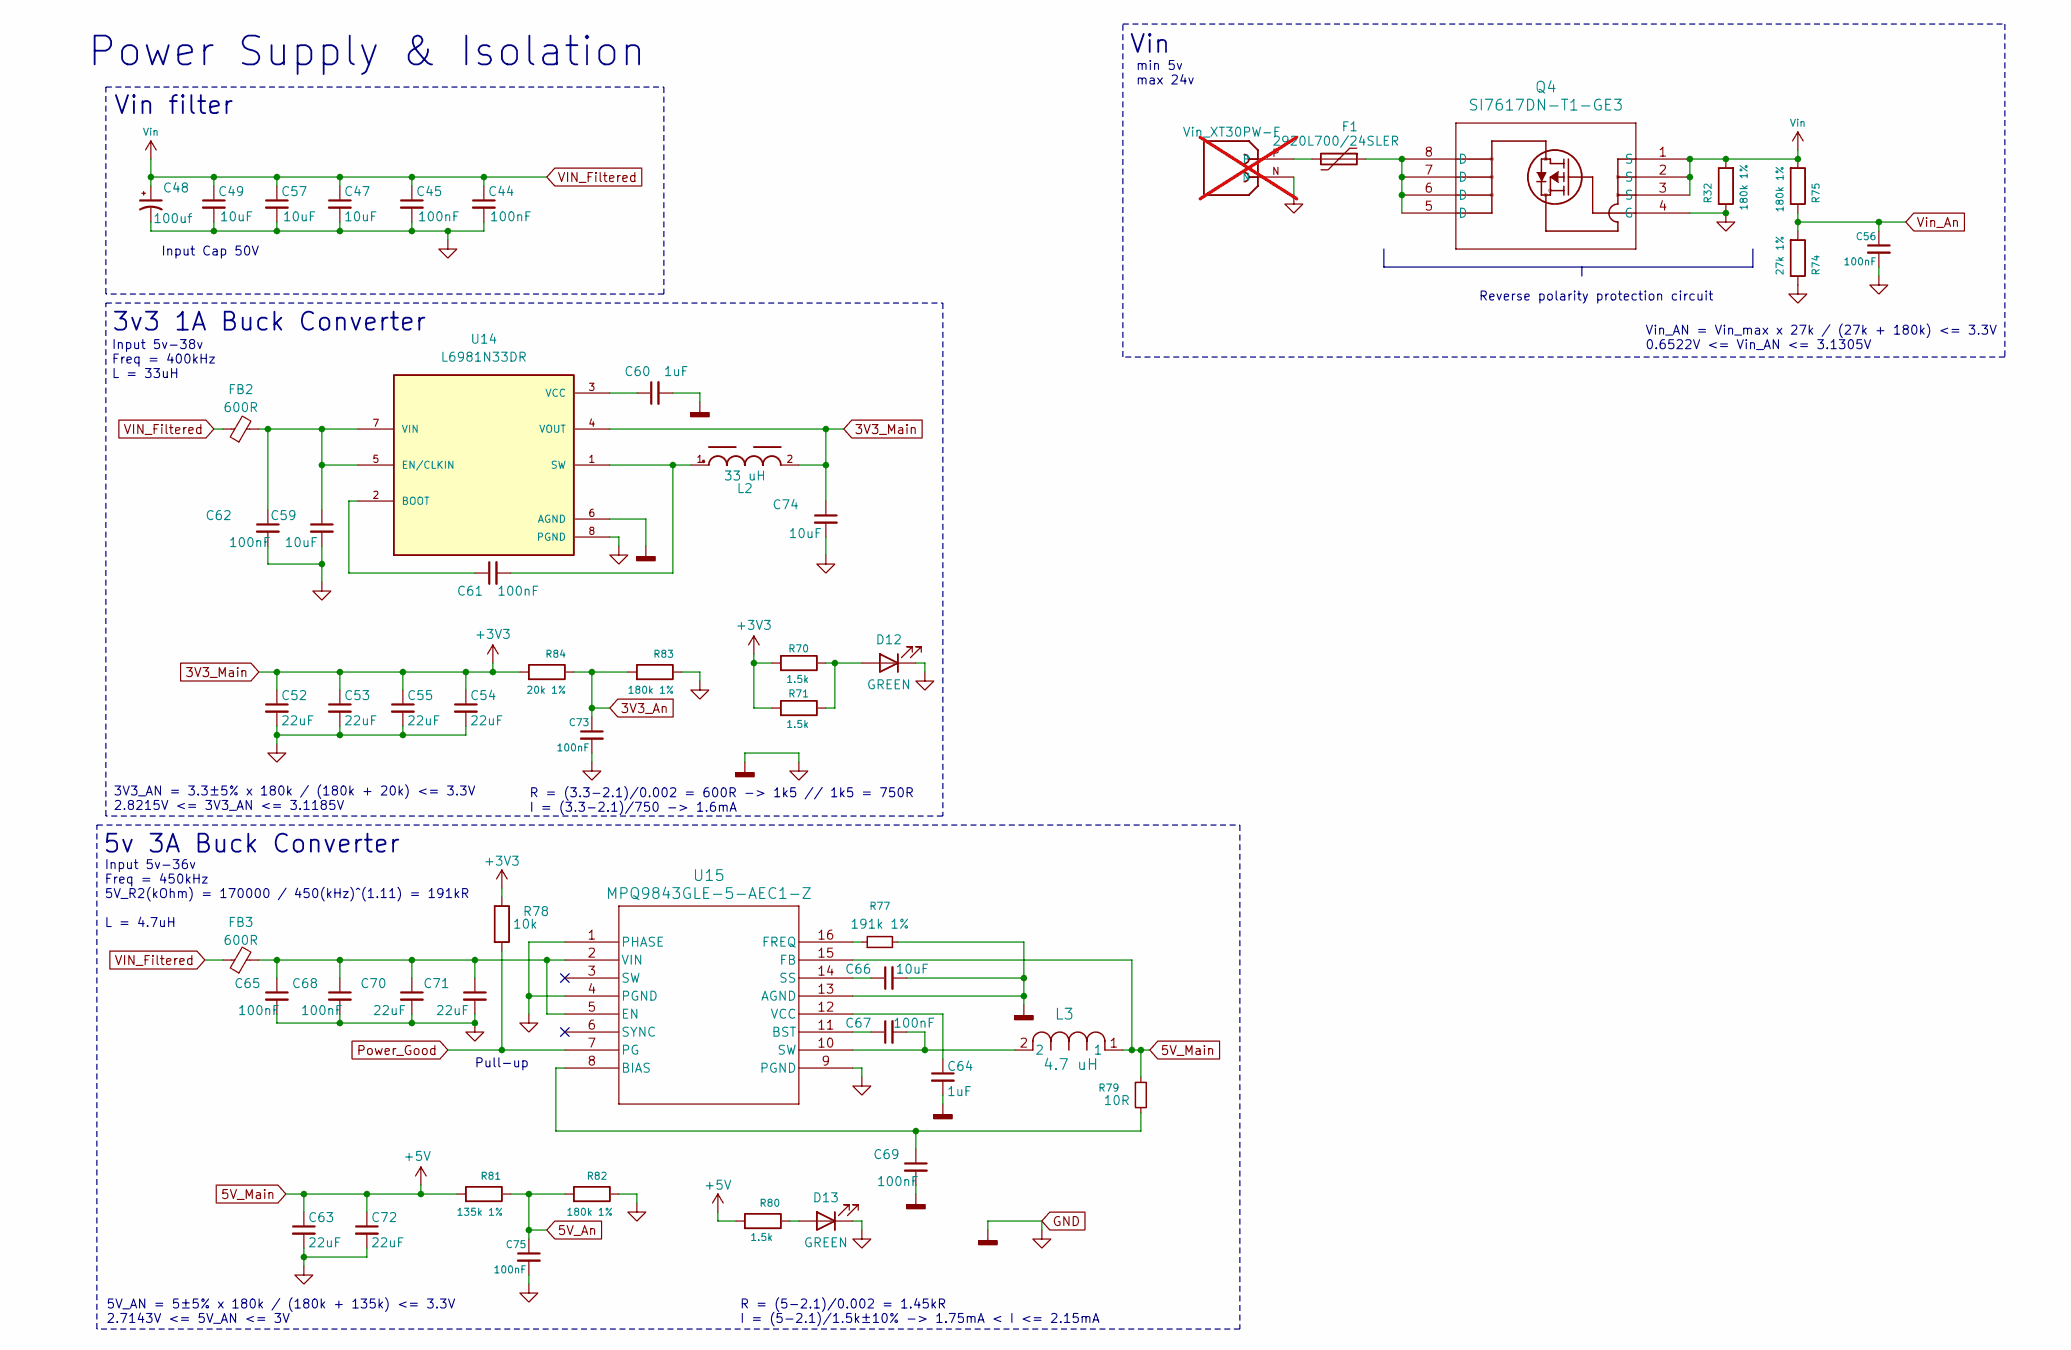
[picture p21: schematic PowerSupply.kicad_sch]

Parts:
C44, C45, C56, C61, C62, C65, C67, C68, C69, C73, C75: 100nF; C_0402_1005Metric; Manufacturer_Part_Number CC0402KRX5R9BB104; DigiKey_Part_Number 311-3342-1-ND
C47, C49, C57, C59, C66, C74: 10uF; C_0603_1608Metric; Manufacturer_Part_Number GMC10X5R106M35NT; DigiKey_Part_Number 4713-GMC10X5R106M35NTTR-ND
C48: 100uf; WCAP-PSHP_8X8.7_DXL_; Manufacturer_Part_Number 875115652007; DigiKey_Part_Number 732-11942-1-ND
C52, C53, C54, C55, C63, C70, C71, C72: 22uF; C_0805_2012Metric; Manufacturer_Part_Number TMK212BBJ226MG-TT; DigiKey_Part_Number 587-6359-1-ND
C60, C64: 1uF; C_0603_1608Metric; Manufacturer_Part_Number C0603C105K4RACTU; DigiKey_Part_Number 399-C0603C105K4RACTUCT-ND
D12, D13: GREEN; LED_QBLP601-AG15; Manufacturer_Part_Number QBLP601-AG15; DigiKey_Part_Number 1516-QBLP601-AG15CT-ND
F1: 2920L700/24SLER; Fuse_2920_7451Metric; Manufacturer_Part_Number 2920L700/24SLER; DigiKey_Part_Number 18-2920L700/24SLERCT-ND
FB2, FB3: 600R; L_1210_3225Metric; Manufacturer_Part_Number FBMH3225HM601NT; DigiKey_Part_Number 587-1755-1-ND
J8: Vin_XT30PW-F; AMASS_XT30PW-F; PARTREV 1.2; not fitted
L2: 33 uH; WE-PD_1245; Manufacturer_Part_Number 7447715330; Digikey 732-2196-1-ND
L3: 4.7 uH; IND_PA4342_PUL; Manufacturer_Part_Number PA4342.472NLT; Digikey 553-3001-1-ND
Q4: SI7617DN-T1-GE3; POWERPAK_1212-8_VIS; Manufacturer_Part_Number SI7617DN-T1-GE3; DigiKey_Part_Number SI7617DN-T1-GE3CT-ND
R32, R75, R82, R83: 180k 1%; R_0603_1608Metric; Manufacturer_Part_Number ERA-3AEB184V; DigiKey_Part_Number P180KDBCT-ND
R70, R71, R80: 1.5k; R_0603_1608Metric; Manufacturer_Part_Number ERA-3AEB152V; DigiKey_Part_Number P1.5KDBCT-ND
R74: 27k 1%; R_0603_1608Metric; Manufacturer_Part_Number RG1608P-273-B-T5; DigiKey_Part_Number RG16P27.0KBCT-ND
R77: 191k 1%; R_0603_1608Metric; Manufacturer_Part_Number RT0603BRD07191KL; DigiKey_Part_Number YAG1553CT-ND
R78: 10k; R_0603_1608Metric; Manufacturer_Part_Number RC0603FR-0710KL; DigiKey_Part_Number 311-10.0KHRCT-ND
R79: 10R; R_0402_1005Metric; Manufacturer_Part_Number CRCW040210R0FKED; DigiKey_Part_Number 541-10.0LCT-ND
R81: 135k 1%; R_0603_1608Metric; Manufacturer_Part_Number RT0603BRD07135KL; DigiKey_Part_Number 13-RT0603BRD07135KLCT-ND
R84: 20k 1%; R_0603_1608Metric; Manufacturer_Part_Number ERA-3AEB203V; DigiKey_Part_Number P20KDBCT-ND
U14: L6981N33DR; SOIC127P600X175-8N; PARTREV 3; DigiKey_Part_Number 497-L6981N33DRCT-ND
U15: MPQ9843GLE-5-AEC1-Z; QFN-16_ MPQ9843; Manufacturer_Part_Number MPQ9843GLE-5-AEC1-Z; DigiKey_Part_Number 1589-MPQ9843GLE-5-AEC1-ZCT-ND

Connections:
3V3_An: C73.1, R83.2, R84.1; also elsewhere on the board
3V3_Main: C52.1, C53.1, C54.1, C55.1, C74.1, L2.2, R70.2, R71.2, R78.1, R84.2, U14.4 (VOUT); also elsewhere on the board
5V_An: C75.1, R81.1, R82.2; also elsewhere on the board
5V_Main: C63.1, C72.1, L3.1, R79.1, R80.2, R81.2, U15.15 (FB); also elsewhere on the board
GND: C44.2, C45.2, C47.2, C48.2, C49.2, C52.2, C53.2, C54.2, C55.2, C56.2, C57.2, C59.2, C60.2, C62.2, C63.2, C64.2, C65.2, C66.2, C68.2, C69.2, C70.2, C71.2, C72.2, C73.2, C74.2, C75.2, D12.1 (K), D13.1 (K), J8.N, Q4.4 (G), R32.1, R74.1, R77.2, R82.1, R83.1, U14.6 (AGND), U14.8 (PGND), U15.1 (PHASE), U15.4 (PGND), U15.9 (PGND), U15.13 (AGND); also elsewhere on the board
unnamed: C67.2, L3.2, U15.10 (SW)
unnamed: D12.2 (A), R70.1, R71.1
unnamed: D13.2 (A), R80.1
unnamed: F1.1, Q4.5 (D), Q4.6 (D), Q4.7 (D), Q4.8 (D), Q4.9 (D)
unnamed: F1.2, J8.P
unnamed: C61.1, U14.2 (BOOT)
unnamed: C59.1, C62.1, FB2.2, U14.5 (EN/CLKIN), U14.7 (VIN)
unnamed: C61.2, L2.1, U14.1 (SW)
unnamed: C60.1, U14.3 (VCC)
unnamed: C69.1, R79.2, U15.8 (BIAS)
unnamed: C67.1, U15.11 (BST)
unnamed: C65.1, C68.1, C70.1, C71.1, FB3.2, U15.2 (VIN), U15.5 (EN)
unnamed: R77.1, U15.16 (FREQ)
unnamed: C66.1, U15.14 (SS)
unnamed: C64.1, U15.12 (VCC)
Power_Good: R78.2, U15.7 (PG); also elsewhere on the board
VIN_Filtered: C44.1, C45.1, C47.1, C48.1, C49.1, C57.1, FB2.1, FB3.1, Q4.1 (S), Q4.2 (S), Q4.3 (S), R32.2, R75.2; also elsewhere on the board
Vin_An: C56.1, R74.2, R75.1; also elsewhere on the board

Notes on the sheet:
Input 5v-38v Freq = 400kHz L = 33uH
Input Cap 50V
Vin_AN = Vin_max x 27k / (27k + 180k) <= 3.3V 0.6522V <= Vin_AN <= 3.1305V
3v3 1A Buck Converter
5V_AN = 5±5% x 180k / (180k + 135k) <= 3.3V 2.7143V <= 5V_AN <= 3V
Vin
Pull-up
R = (3.3-2.1)/0.002 = 600R -> 1k5 // 1k5 = 750R I = (3.3-2.1)/750 -> 1.6mA
Reverse polarity protection circuit
3V3_AN = 3.3±5% x 180k / (180k + 20k) <= 3.3V 2.8215V <= 3V3_AN <= 3.1185V
Vin filter
Input 5v-36v Freq = 450kHz 5V_R2(kOhm) = 170000 / 450(kHz)^(1.11) = 191kR L = 4.7uH
R = (5-2.1)/0.002 = 1.45kR I = (5-2.1)/1.5k±10% -> 1.75mA < I <= 2.15mA
min 5v max 24v
Power Supply & Isolation
5v 3A Buck Converter

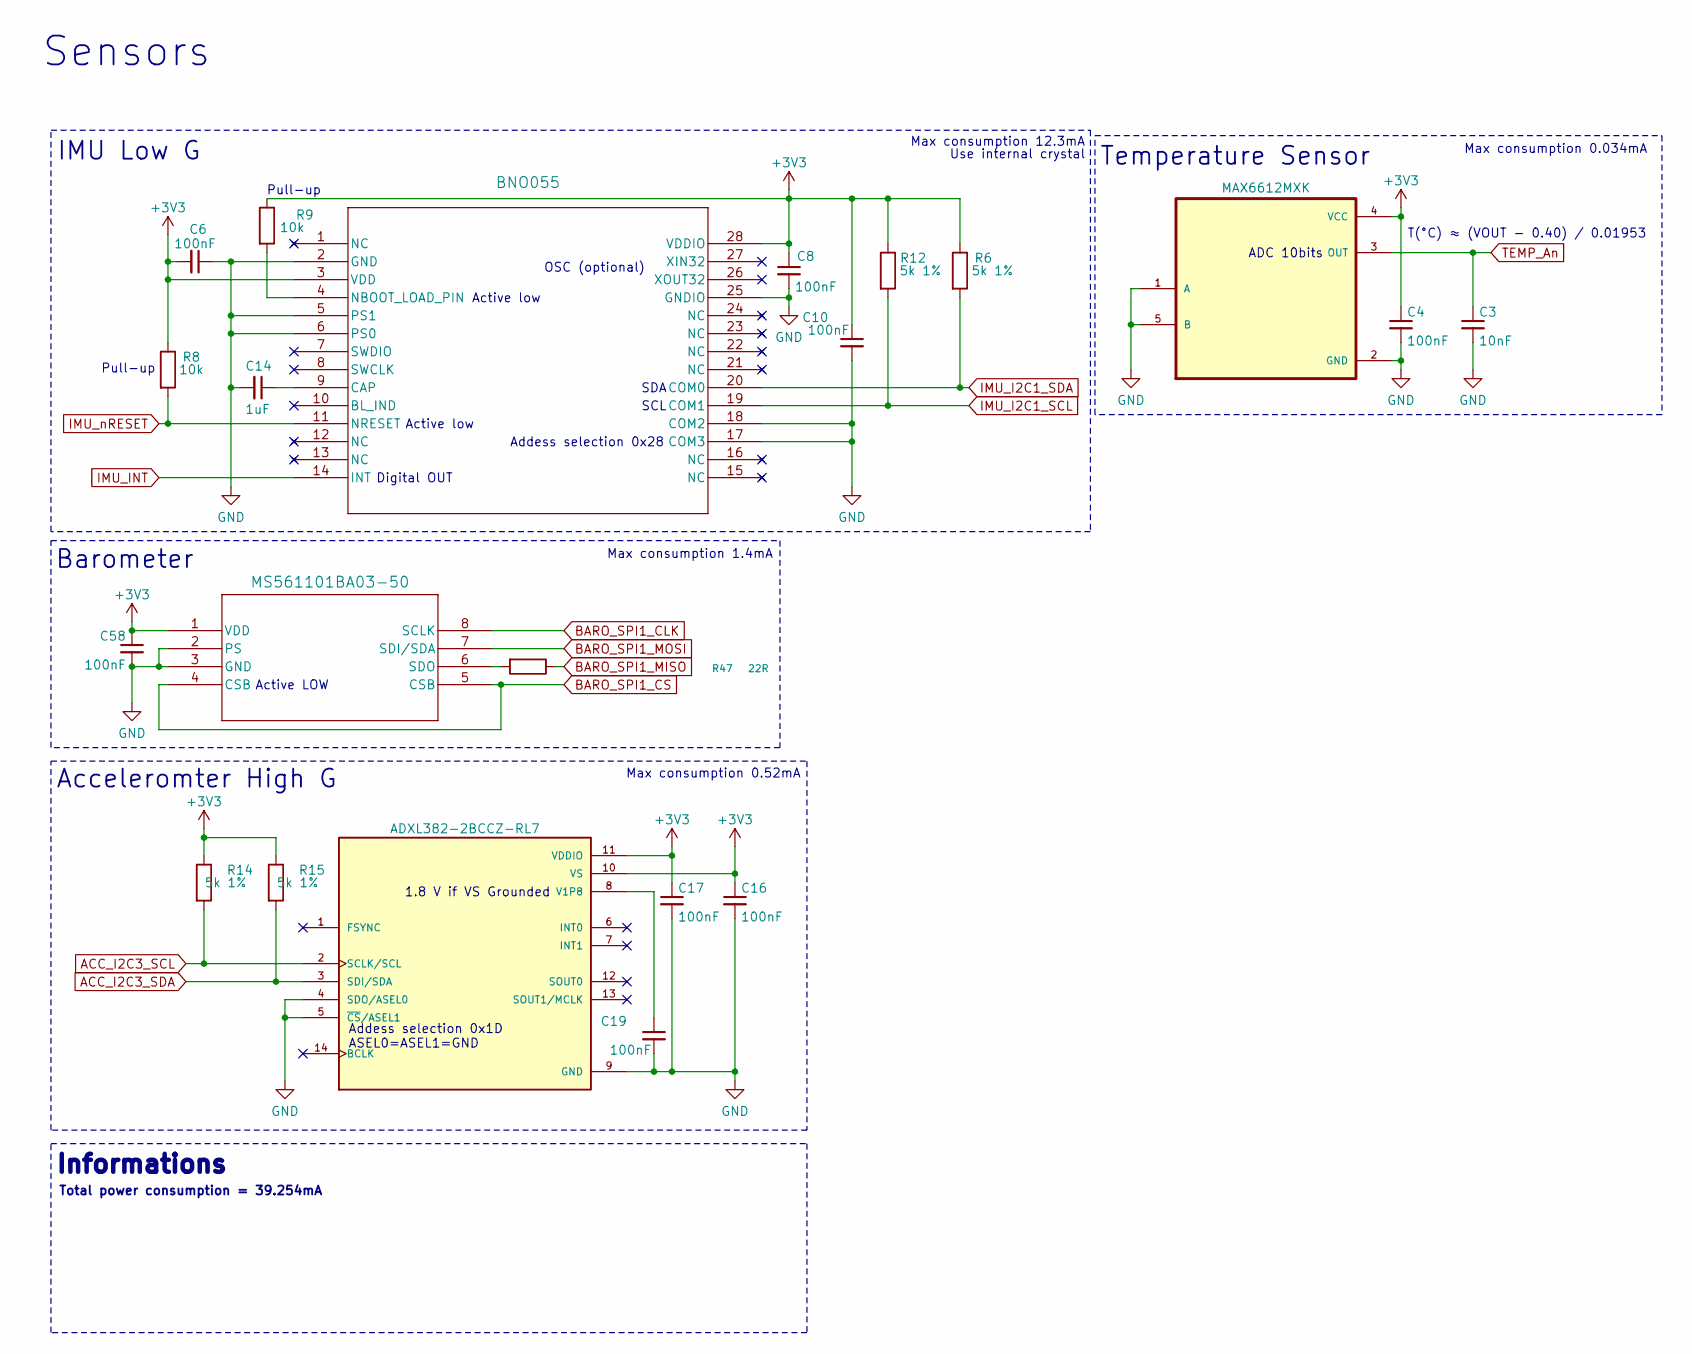
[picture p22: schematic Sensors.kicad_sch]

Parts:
C3: 10nF; C_0402_1005Metric; Manufacturer_Part_Number GRM155R71C103KA01D; DigiKey_Part_Number 490-1313-1-ND
C4, C6, C8, C10, C16, C17, C19, C58: 100nF; C_0402_1005Metric; Manufacturer_Part_Number CC0402KRX5R9BB104; DigiKey_Part_Number 311-3342-1-ND
C14: 1uF; C_0603_1608Metric; Manufacturer_Part_Number C0603C105K4RACTU; DigiKey_Part_Number 399-C0603C105K4RACTUCT-ND
R6, R12, R14, R15: 5k 1%; R_0603_1608Metric; Manufacturer_Part_Number MCT06030D5001BP500; DigiKey_Part_Number 541-MCT06030D5001BP500CT-ND
R8, R9: 10k; R_0603_1608Metric; Manufacturer_Part_Number RC0603FR-0710KL; DigiKey_Part_Number 311-10.0KHRCT-ND
R47: 22R; R_0402_1005Metric; Manufacturer_Part_Number AC0402FR-0722RL; DigiKey_Part_Number YAG3460CT-ND
U3: MAX6612MXK; SOT65P210X110-5N; Manufacturer_Part_Number MAX6612MXK+T; DigiKey_Part_Number MAX6612MXK+TCT-ND
U4: BNO055; QFN_BNO055_BOS; Manufacturer_Part_Number BNO055; DigiKey_Part_Number 828-1058-1-ND
U5: ADXL382-2BCCZ-RL7; XDCR_ADXL382-2BCCZ-RL7; PARTREV 0; DigiKey_Part_Number 505-ADXL382-2BCCZ-RL7CT-ND
U13: MS561101BA03-50; SON8_MS5611_TEC; Manufacturer_Part_Number MS561101BA03-50; DigiKey_Part_Number 223-1622-1-ND

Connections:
3V3_Main: C4.1, C6.2, C8.1, C10.1, C16.1, C17.1, C58.1, R6.1, R8.1, R9.1, R12.1, R14.1, R15.1, U3.4 (VCC), U4.3 (VDD), U4.28 (VDDIO), U5.10 (VS), U5.11 (VDDIO), U13.1 (VDD); also elsewhere on the board
ACC_I2C3_SCL: R14.2, U5.2 (SCLK/SCL); also elsewhere on the board
ACC_I2C3_SDA: R15.2, U5.3 (SDI/SDA); also elsewhere on the board
BARO_SPI1_CLK: U13.8 (SCLK); also elsewhere on the board
BARO_SPI1_CS: U13.4 (CSB), U13.5 (CSB); also elsewhere on the board
BARO_SPI1_MISO: R47.1; also elsewhere on the board
BARO_SPI1_MOSI: U13.7 (SDI/SDA); also elsewhere on the board
GND: C3.2, C4.2, C6.1, C8.2, C10.2, C14.2, C16.2, C17.2, C19.2, C58.2, U3.1 (A), U3.2 (GND), U3.5 (B), U4.2 (GND), U4.5 (PS1), U4.6 (PS0), U4.17 (COM3), U4.18 (COM2), U4.25 (GNDIO), U5.4 (SDO/ASEL0), U5.5 (~CS/ASEL1), U5.9 (GND), U13.2 (PS), U13.3 (GND); also elsewhere on the board
IMU_I2C1_SCL: R12.2, U4.19 (COM1); also elsewhere on the board
IMU_I2C1_SDA: R6.2, U4.20 (COM0); also elsewhere on the board
IMU_INT: U4.14 (INT); also elsewhere on the board
IMU_nRESET: R8.2, U4.11 (NRESET); also elsewhere on the board
unnamed: C14.1, U4.9 (CAP)
unnamed: R9.2, U4.4 (NBOOT_LOAD_PIN)
unnamed: C19.1, U5.8 (V1P8)
unnamed: R47.2, U13.6 (SDO)
TEMP_An: C3.1, U3.3 (OUT); also elsewhere on the board

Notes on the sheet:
OSC (optional)
Max consumption 0.52mA
Active low
Max consumption 12.3mA
Total power consumption = 39.254mA
Pull-up
SCL
Temperature Sensor
T(°C) ≈ (VOUT - 0.40) / 0.01953
Addess selection 0x1D ASEL0=ASEL1=GND
Informations
1.8 V if VS Grounded
Max consumption 0.034mA
Sensors
Max consumption 1.4mA
Acceleromter High G
Digital OUT
Barometer
Addess selection 0x28
Use internal crystal
Active LOW
SDA
ADC 10bits
IMU Low G

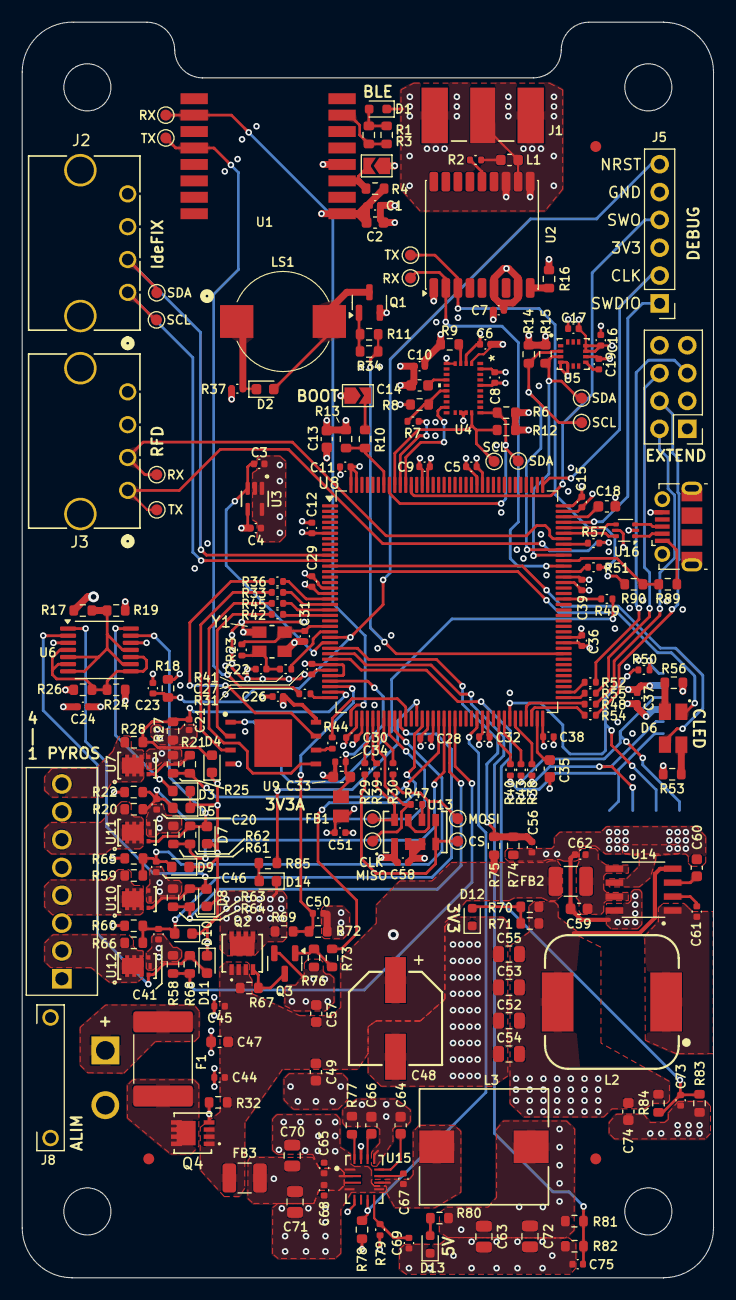
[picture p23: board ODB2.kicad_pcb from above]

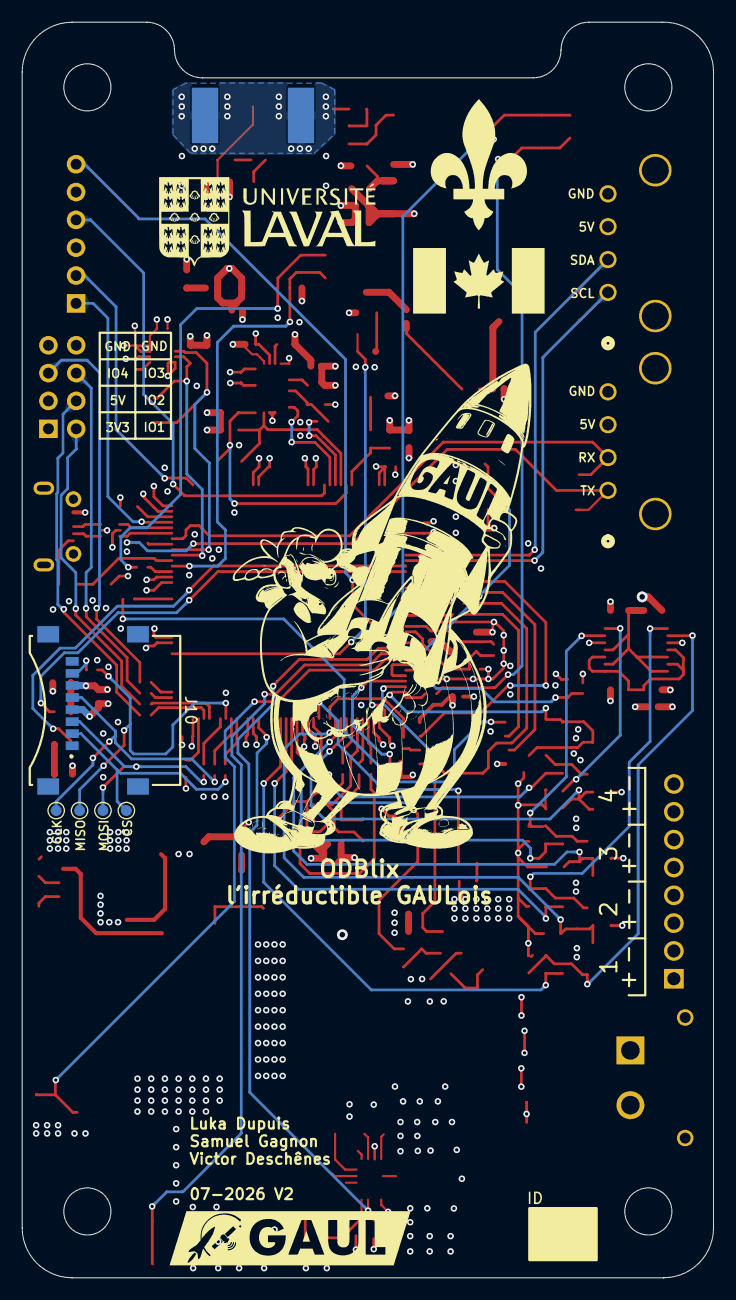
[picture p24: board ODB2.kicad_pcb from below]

Board: 6 copper layers, 63.1 x 114.6 mm, 233 parts (5 on the bottom side), 139 nets.

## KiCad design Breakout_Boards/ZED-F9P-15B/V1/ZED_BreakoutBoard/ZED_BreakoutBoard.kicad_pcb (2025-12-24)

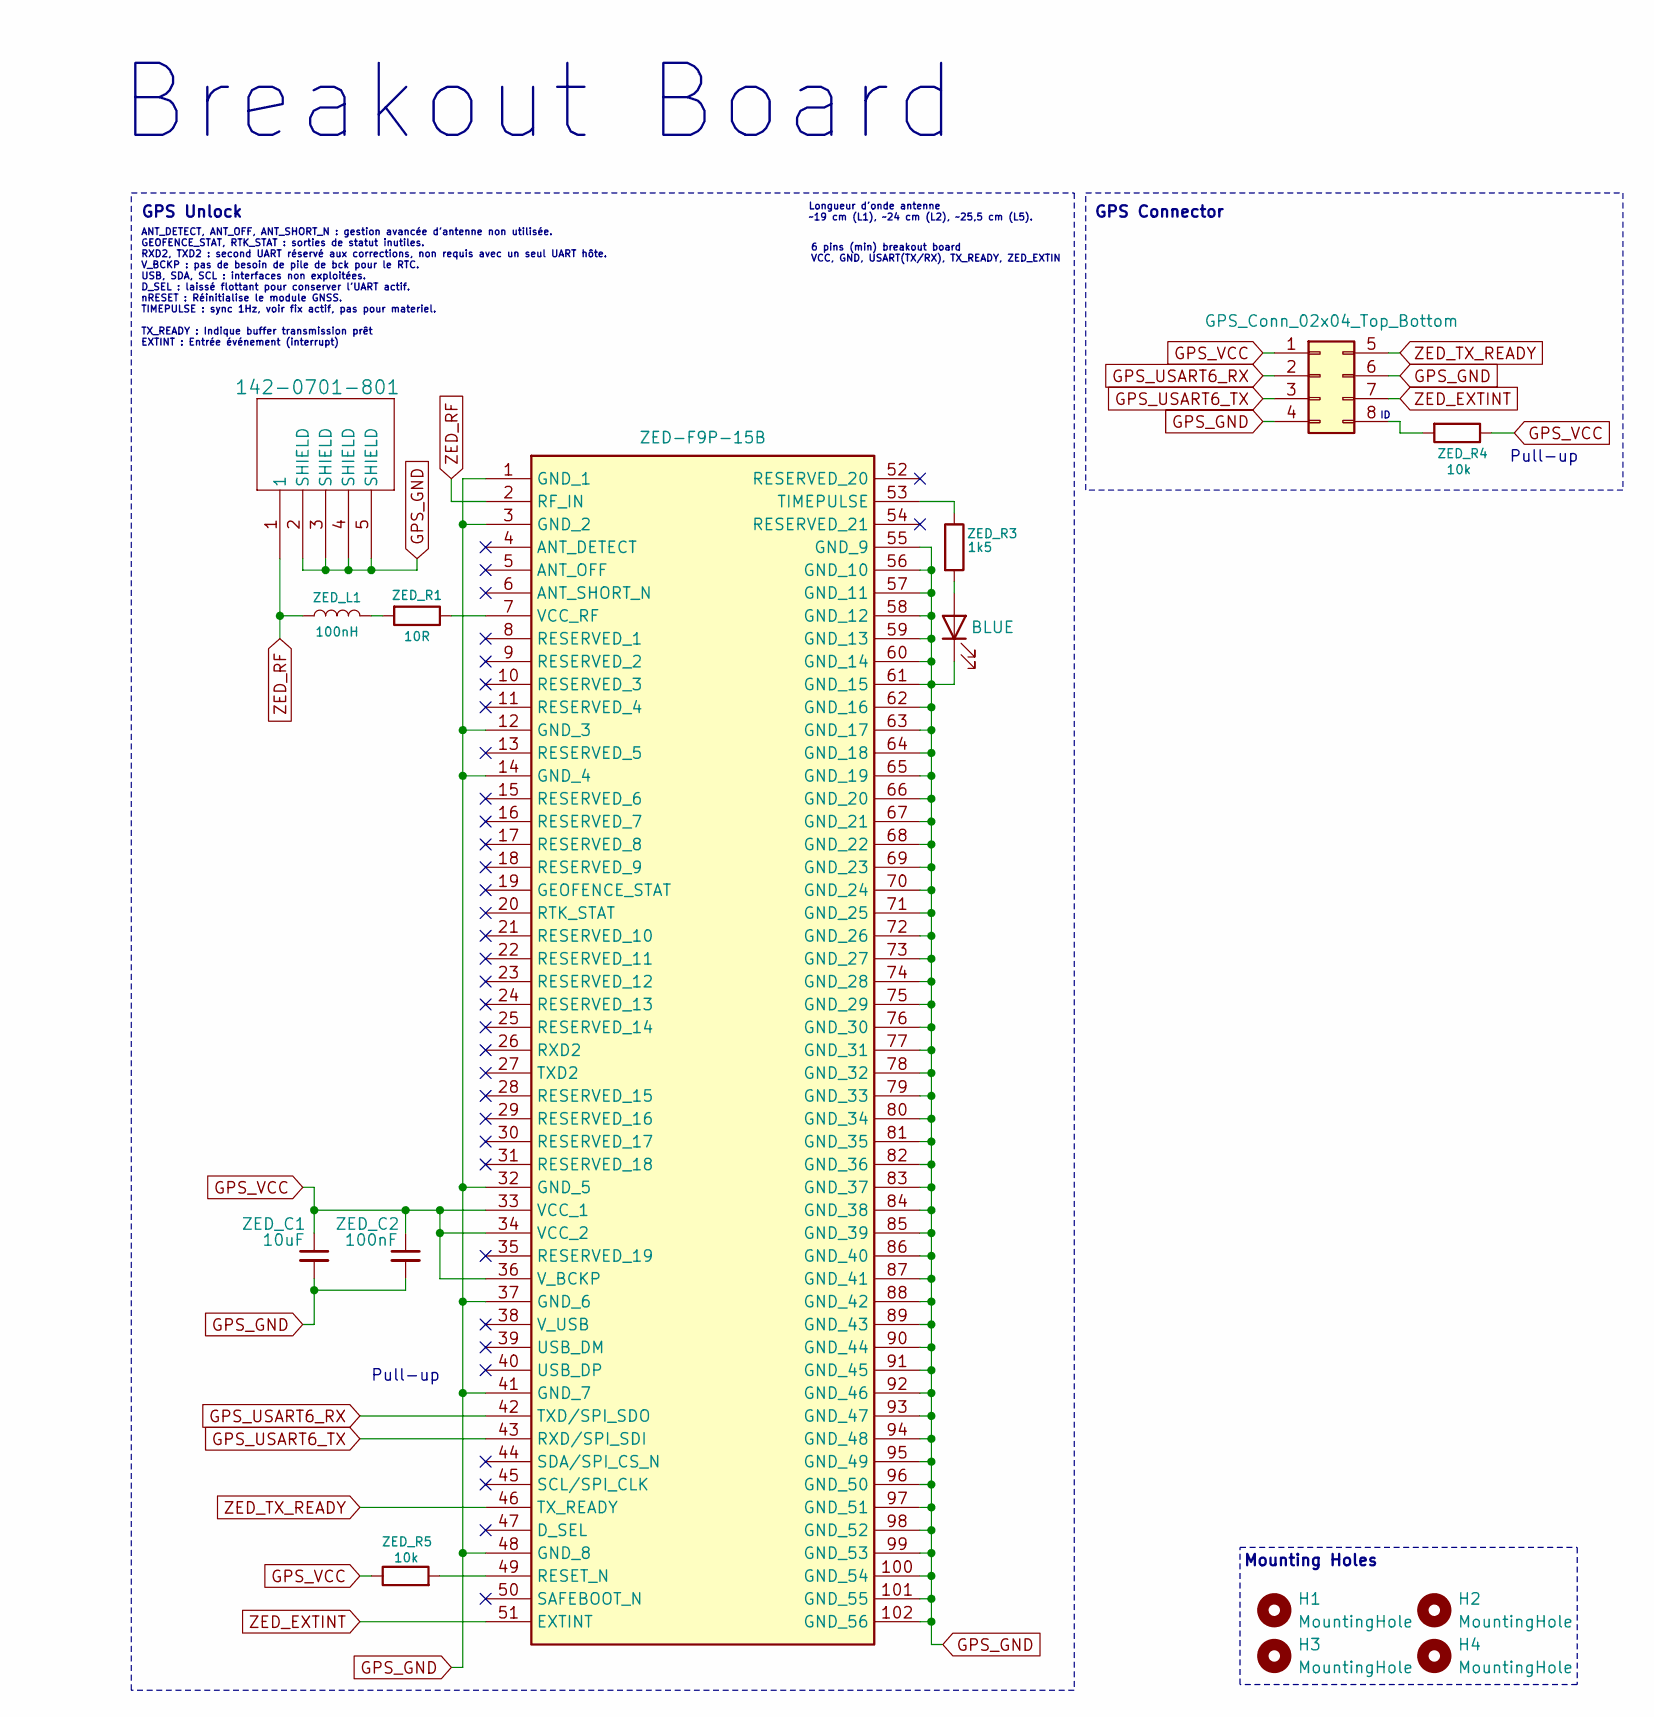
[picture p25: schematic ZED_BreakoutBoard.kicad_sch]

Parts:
H1, H2, H3, H4: MountingHole; MountingHole_2.2mm_M2
IC1: ZED-F9P-15B; ZEDF9P15B; Mouser Part Number 377-ZED-F9P-15B
J1: 142-0701-801; CONN_142-0701-801
J2: GPS_Conn_02x04_Top_Bottom; PinHeader_2x04_P2.54mm_Vertical
ZED_C1: 10uF; C_0603_1608Metric
ZED_C2: 100nF; C_0603_1608Metric
ZED_L1: 100nH; L_0603_1608Metric
ZED_LED1: BLUE; LED_0603_1608Metric
ZED_R1: 10R; R_0603_1608Metric
ZED_R3: 1k5; R_0603_1608Metric
ZED_R4, ZED_R5: 10k; R_0603_1608Metric

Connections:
GPS_GND: IC1.1 (GND_1), IC1.3 (GND_2), IC1.12 (GND_3), IC1.14 (GND_4), IC1.32 (GND_5), IC1.37 (GND_6), IC1.41 (GND_7), IC1.48 (GND_8), IC1.55 (GND_9), IC1.56 (GND_10), IC1.57 (GND_11), IC1.58 (GND_12), IC1.59 (GND_13), IC1.60 (GND_14), IC1.61 (GND_15), IC1.62 (GND_16), IC1.63 (GND_17), IC1.64 (GND_18), IC1.65 (GND_19), IC1.66 (GND_20), IC1.67 (GND_21), IC1.68 (GND_22), IC1.69 (GND_23), IC1.70 (GND_24), IC1.71 (GND_25), IC1.72 (GND_26), IC1.73 (GND_27), IC1.74 (GND_28), IC1.75 (GND_29), IC1.76 (GND_30), IC1.77 (GND_31), IC1.78 (GND_32), IC1.79 (GND_33), IC1.80 (GND_34), IC1.81 (GND_35), IC1.82 (GND_36), IC1.83 (GND_37), IC1.84 (GND_38), IC1.85 (GND_39), IC1.86 (GND_40), IC1.87 (GND_41), IC1.88 (GND_42), IC1.89 (GND_43), IC1.90 (GND_44), IC1.91 (GND_45), IC1.92 (GND_46), IC1.93 (GND_47), IC1.94 (GND_48), IC1.95 (GND_49), IC1.96 (GND_50), IC1.97 (GND_51), IC1.98 (GND_52), IC1.99 (GND_53), IC1.100 (GND_54), IC1.101 (GND_55), IC1.102 (GND_56), J1.2 (SHIELD), J1.3 (SHIELD), J1.4 (SHIELD), J1.5 (SHIELD), J2.4, J2.6, ZED_C1.2, ZED_C2.2, ZED_LED1.1 (K)
GPS_USART6_RX: IC1.42 (TXD/SPI_SDO), J2.2
GPS_USART6_TX: IC1.43 (RXD/SPI_SDI), J2.3
GPS_VCC: IC1.33 (VCC_1), IC1.34 (VCC_2), IC1.36 (V_BCKP), J2.1, ZED_C1.1, ZED_C2.1, ZED_R4.1, ZED_R5.1
unnamed: IC1.49 (RESET_N), ZED_R5.2
unnamed: IC1.53 (TIMEPULSE), ZED_R3.1
unnamed: IC1.7 (VCC_RF), ZED_R1.1
unnamed: J2.8, ZED_R4.2
unnamed: ZED_L1.2, ZED_R1.2
unnamed: ZED_LED1.2 (A), ZED_R3.2
ZED_EXTINT: IC1.51 (EXTINT), J2.7
ZED_RF: IC1.2 (RF_IN), J1.1, ZED_L1.1
ZED_TX_READY: IC1.46 (TX_READY), J2.5

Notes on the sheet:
Mounting Holes
GPS Connector
Pull-up
GPS Unlock
Breakout Board
6 pins (min) breakout board VCC, GND, USART(TX/RX), TX_READY, ZED_EXTIN
ANT_DETECT, ANT_OFF, ANT_SHORT_N : gestion avancée d'antenne non utilisée. GEOFENCE_STAT, RTK_STAT : sorties de statut inutiles. RXD2, TXD2 : second UART réservé aux corrections, non requis avec un seul UART hôte. V_BCKP : pas de besoin de pile de bck pour le RTC. USB, SDA, SCL : interfaces non exp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
Longueur d'onde antenne ~19 cm (L1), ~24 cm (L2), ~25,5 cm (L5).

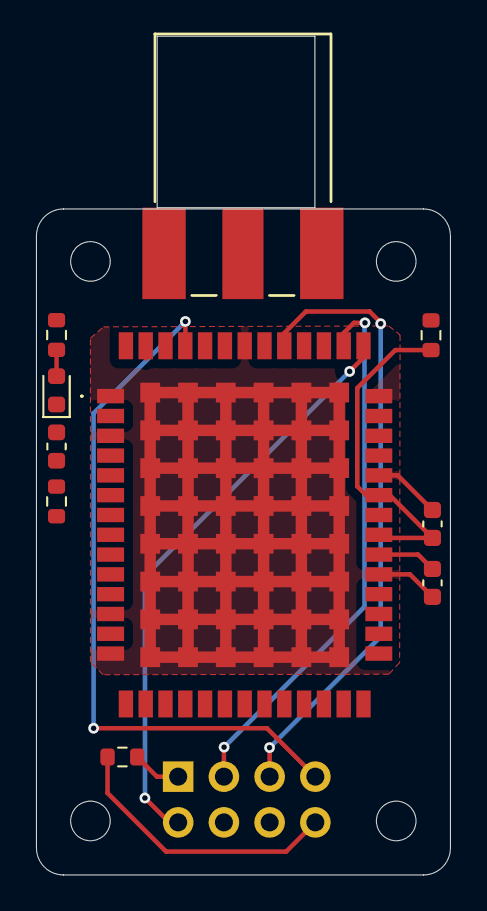
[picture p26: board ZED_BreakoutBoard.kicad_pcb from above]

Board: 2 copper layers, 23.0 x 37.0 mm, 15 parts (1 on the bottom side), 13 nets.

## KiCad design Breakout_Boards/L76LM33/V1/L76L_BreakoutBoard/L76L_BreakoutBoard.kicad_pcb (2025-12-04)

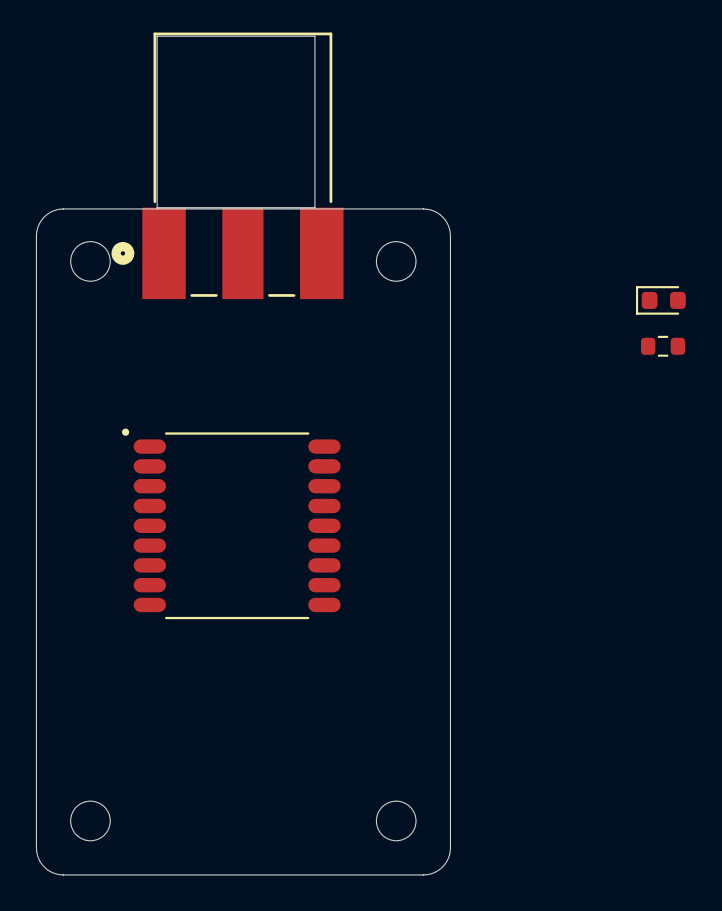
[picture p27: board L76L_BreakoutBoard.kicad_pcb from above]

Board: 2 copper layers, 23.0 x 46.6 mm, 8 parts (0 on the bottom side), 4 nets, no tracks yet.

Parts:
H1, H2, H3, H4: MountingHole; MountingHole_2.2mm_M2
J1: 142-0701-801; CONN_142-0701-801
L76LM33_R3: 1k5; R_0603_1608Metric
U1: L76L-M33; XCVR_L76L-M33
ZED_LED1: BLUE; LED_0603_1608Metric

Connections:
GPS_GND: J1.2 (SHIELD), J1.3 (SHIELD), J1.4 (SHIELD), J1.5 (SHIELD), U1.1 (GND), U1.9 (RESET), U1.10 (GND__1), U1.12 (GND__2), ZED_LED1.1 (K)
GPS_VCC: L76LM33_R3.1, U1.6 (V_BCKP), U1.8 (VCC)
L76LM33_RF: J1.1, U1.11 (RF_IN)
unnamed: L76LM33_R3.2, ZED_LED1.2 (A)

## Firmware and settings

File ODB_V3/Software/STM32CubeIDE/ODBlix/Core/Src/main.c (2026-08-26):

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
/* Includes ------------------------------------------------------------------*/
#include "main.h"
#include "fatfs.h"
#include "usb_device.h"

/* USER CODE BEGIN Includes */
#include "odb.h"
#include "Systems/tasks.h"
#include "Systems/scheduler.h"
#include "Tools/profiler.h"
#include "Systems/config.h"
#include "Systems/flight_fsm.h"
#include "Drivers/adxl382.h"
#include "Drivers/bno055.h"
#include "Drivers/hm11.h"
#include "Drivers/ms5611.h"
#include "Drivers/bno055.h"
#include "Drivers/l76lm33.h"
#include "Drivers/ltste682krkgwt.h"
#include "Drivers/pyros.h"
#include "Drivers/rfd900x.h"
#include "Drivers/smtb0927twr.h"
#include "Drivers/system_measurements.h"
#include "Drivers/w25q512jveim.h"
#include "Utils/reboot_manager.h"
/* USER CODE END Includes */

ADC_HandleTypeDef hadc1;
DMA_HandleTypeDef hdma_adc1;

I2C_HandleTypeDef hi2c1;
I2C_HandleTypeDef hi2c2;
I2C_HandleTypeDef hi2c3;
DMA_HandleTypeDef hdma_i2c1_rx;

QSPI_HandleTypeDef hqspi;

SPI_HandleTypeDef hspi1;
SPI_HandleTypeDef hspi5;
DMA_HandleTypeDef hdma_spi5_tx;
DMA_HandleTypeDef hdma_spi5_rx;

TIM_HandleTypeDef htim2;
TIM_HandleTypeDef htim4;
TIM_HandleTypeDef htim5;

UART_HandleTypeDef huart1;
UART_HandleTypeDef huart2;
UART_HandleTypeDef huart6;
DMA_HandleTypeDef hdma_usart1_tx;
DMA_HandleTypeDef hdma_usart2_tx;
DMA_HandleTypeDef hdma_usart6_rx;

/* USER CODE BEGIN PV */
adxl382_t adxl382 = {
    .hi2c = &hi2c3,
    .mode = ADXL382_MODE_HP,
	.range = ADXL382_RANGE_30G,
	.filters_cfg = {
		.iir7_bypass  = false,
		.sinc_rate    = ADXL382_SINC_32X,
		.iir1_enable  = false,
		.round_mode   = ADXL382_ROUND_TRUNCATE,
		.dcf_bypass   = false,
		.eq_bypass    = true,
		.lpf_mode     = ADXL382_LPF_ODR_16,
		.hpf_path     = ADXL382_HPF_DSM,
		.hpf_corner   = ADXL382_HPF_NONE,
		.or_behavior  = ADXL382_OR_HOLD_PREV
	},
	.x_axis_offset = {
		.c0 = 0.0f,
		.c1 = 0.0f,
		.c2 = 0.0f,
		.c3 = 0.0f,
	},
	.y_axis_offset = {
		.c0 = 0.0f,
		.c1 = 0.0f,
		.c2 = 0.0f,
		.c3 = 0.0f,
	},
	.z_axis_offset = {
		.c0 = 0.0f,
		.c1 = 0.0f,
		.c2 = 0.0f,
		.c3 = 0.0f,
	},
	.faces_offset = {
		.scale_matrix = {
			{1.0f, 0.0f, 0.0f},
			{0.0f, 1.0f, 0.0f},
			{0.0f, 0.0f, 1.0f}
		},
		.bias = {0.0f, 0.0f, 0.0f}
	}
};
bno055_t bno055 = {
    .hi2c = &hi2c1,
    .drdy_port = IMU_INT_GPIO_Port,
    .drdy_pin = IMU_INT_Pin,
    .rst_port = IMU_nReset_GPIO_Port,
    .rst_pin = IMU_nReset_Pin,
    .op_mode = BNO055_OP_MODE_NDOF,
    .acc_range = BNO055_ACC_RANGE_4G, // effective only if using a non-fusion mode, else its set 4G by IMU's MCU
};
hm11_t hm11 = {
    .huart = &huart2,
    .baudrate = HM11_BAUD_115200,
	.tx_power = HM11_NORMAL_TX_POWER,
};
l76lm33_t l76lm33 = {
	.huart = &huart6,
};
critical_led_t critical_led = {
	.current_color = NONE,
	.r_port = CriticalLED_R_GPIO_Port,
	.g_port = CriticalLED_G_GPIO_Port,
	.r_pin = CriticalLED_R_Pin,
	.g_pin = CriticalLED_G_Pin,
};
ms5611_t ms5611 = {
    .spi = &hspi1,
    .cs_port = BARO_SPI1_CS_GPIO_Port,
    .cs_pin = BARO_SPI1_CS_Pin,
};
pyro_t pyros[4] = {
    {
        .fire_port = Fire_1_GPIO_Port,
        .fire_pin = Fire_1_Pin,
        .channel = PYRO_1,
        .is_connected = false,
        .is_fire = false,
    },
    {
        .fire_port = Fire_2_GPIO_Port,
        .fire_pin = Fire_2_Pin,
        .channel = PYRO_2,
        .is_connected = false,
        .is_fire = false,
    },
    {
        .fire_port = Fire_3_GPIO_Port,
        .fire_pin = Fire_3_Pin,
        .channel = PYRO_3,
        .is_connected = false,
        .is_fire = false,
    },
    {
        .fire_port = Fire_4_GPIO_Port,
        .fire_pin = Fire_4_Pin,
        .channel = PYRO_4,
        .is_connected = false,
        .is_fire = false,
    }
};
rfd900x_t rfd900x = {
    .huart = &huart1,
};
system_measurements_t system_measurements = {
	.hadc = &hadc1,
	.htim = &htim2,
	.pg_port = Power_Good_GPIO_Port,
	.pg_pin = Power_Good_Pin
};
buzzer_t buzzer = {
	.htim = &htim4,
	.channel = TIM_CHANNEL_1
};
volatile uint16_t adc_buffer[DMA_INDEX_SIZE];
w25q_t w25q = {
	.hqspi = &hqspi,
};
idefix_t idefix = {
	.hi2c = &hi2c2,
};
mem2067_t mem2067 = {};
odb_data_t flight_data = {0};
odb_stats_t flight_stats = {0};

/* USER CODE END PV */

void SystemClock_Config(void);
static void MX_GPIO_Init(void);
static void MX_DMA_Init(void);
static void MX_I2C1_Init(void);
static void MX_I2C2_Init(void);
static void MX_SPI1_Init(void);
static void MX_SPI5_Init(void);
static void MX_USART1_UART_Init(void);
static void MX_USART2_UART_Init(void);
static void MX_USART6_UART_Init(void);
static void MX_QUADSPI_Init(void);
static void MX_ADC1_Init(void);
static void MX_I2C3_Init(void);
static void MX_TIM2_Init(void);
static void MX_TIM4_Init(void);
static void MX_TIM5_Init(void);
/* USER CODE BEGIN 0 */
int _write(int file, char *ptr, int len) {
    int DataIdx;
    for (DataIdx = 0; DataIdx < len; DataIdx++) {
        ITM_SendChar(*ptr++);
    }
    return len;
}
/* USER CODE END 0 */

/**
  * @brief  The application entry point.
  * @retval int
  */
int main(void)
{

  /* MCU Configuration--------------------------------------------------------*/

  /* Reset of all peripherals, Initializes the Flash interface and the Systick. */
  HAL_Init();

  /* Configure the system clock */
  SystemClock_Config();

  /* Initialize all configured peripherals */
  MX_GPIO_Init();
  MX_DMA_Init();
  MX_I2C1_Init();
  MX_I2C2_Init();
  MX_SPI1_Init();
  MX_SPI5_Init();
  MX_USART1_UART_Init();
  MX_USART2_UART_Init();
  MX_USART6_UART_Init();
  MX_QUADSPI_Init();
  MX_USB_DEVICE_Init();
  MX_ADC1_Init();
  MX_I2C3_Init();
  MX_FATFS_Init();
  MX_TIM2_Init();
  MX_TIM4_Init();
  MX_TIM5_Init();
  /* USER CODE BEGIN 2 */
  HAL_Delay(2000);
  DWT_Init();
  ODB_Init(&flight_data, &flight_stats);
  RebootManager_Init();
  Scheduler_Init();
  Scheduler_AddTask("Reboot", Task_RebootManager, TASK_REBOOT_MANAGER_FREQ_MS);
  Scheduler_AddTask("Data_Update", Task_DataUpdate, TASK_DATA_UPDATE_FREQ_MS);
  Scheduler_AddTask("FSM", Task_ExecuteFsm, TASK_FSM_FREQ_MS);
  Scheduler_AddTask("Logger", Task_Logger, TASK_LOGGER_FREQ_MS);
  Scheduler_AddTask("Telemetry", Task_Telemetry, TASK_TELEMETRY_FREQ_MS);
  Scheduler_AddTask("Idefix", Task_Idefix, TASK_IDEFIX_FREQ_MS);
  Scheduler_AddTask("BTRx", Task_BluetoothAppRx, TASK_BLUETOOTH_APP_RX_FREQ_MS);
  Scheduler_AddTask("BTTx", Task_BluetoothAppTx, TASK_BLUETOOTH_APP_TX_FREQ_MS);
  Scheduler_SetActive("Reboot", true);
  Scheduler_SetActive("Data_Update", true);
  Scheduler_SetActive("FSM", true);
  Scheduler_SetActive("Logger", true);
  Scheduler_SetActive("Telemetry", true);
  Scheduler_SetActive("Idefix", false);
  Scheduler_SetActive("BTRx", true);
  Scheduler_SetActive("BTTx", true);
  /* USER CODE END 2 */

  /* Infinite loop */
  /* USER CODE BEGIN WHILE */
  while (1)
  {
    /* USER CODE END WHILE */

    /* USER CODE BEGIN 3 */
    Scheduler_Run();
  }
  /* USER CODE END 3 */
}

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


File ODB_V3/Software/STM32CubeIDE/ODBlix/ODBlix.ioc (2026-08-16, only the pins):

Mcu.UserName=STM32F412ZGTx
PA0.GPIO_Label=PA_An
PA0.Signal=ADCx_IN0
PA1.GPIO_Label=Sense_4
PA1.Signal=ADCx_IN1
PA10.GPIO_Label=RFD_USART1_RX
PA10.Signal=USART1_RX
PA11.Signal=USB_OTG_FS_DM
PA12.Signal=USB_OTG_FS_DP
PA13.GPIO_Label=SYS_SWDIO
PA13.Signal=SYS_JTMS-SWDIO
PA14.GPIO_Label=SYS_SWCLK
PA14.Signal=SYS_JTCK-SWCLK
PA2.GPIO_Label=BT_USART2_TX
PA2.Signal=USART2_TX
PA3.GPIO_Label=BT_USART2_RX
PA3.Signal=USART2_RX
PA4.GPIO_Label=BARO_SPI1_CS
PA4.Signal=GPIO_Output
PA5.GPIO_Label=BARO_SPI1_CLK
PA5.Signal=SPI1_SCK
PA6.GPIO_Label=BARO_SPI1_MISO
PA6.Signal=SPI1_MISO
PA7.GPIO_Label=BARO_SPI1_MOSI
PA7.Signal=SPI1_MOSI
PA8.GPIO_Label=ACC_I2C3_SCL
PA8.Signal=I2C3_SCL
PA9.GPIO_Label=RFD_USART1_TX
PA9.Signal=USART1_TX
PB0.GPIO_Label=Sense_1
PB0.Signal=ADCx_IN8
PB1.GPIO_Label=MEM_QSPI_CLK
PB1.Signal=QUADSPI_CLK
PB10.GPIO_Label=EXTEND_IO1
PB10.Signal=USART3_TX
PB11.GPIO_Label=EXTEND_IO2
PB11.Signal=USART3_RX
PB12.GPIO_Label=EXTEND_IO3
PB12.Signal=GPIO_Input
PB13.GPIO_Label=EXTEND_IO4
PB13.Signal=GPIO_Input
PB3.GPIO_Label=SYS_SWO
PB3.Signal=SYS_JTDO-SWO
PB4.GPIO_Label=IMU_INT
PB4.Signal=GPXTI4
PB5.GPIO_Label=IMU_nReset
PB5.Signal=GPIO_Output
PB6.GPIO_Label=IMU_I2C1_SCL
PB6.Signal=I2C1_SCL
PB7.GPIO_Label=IMU_I2C1_SDA
PB7.Signal=I2C1_SDA
PC0.GPIO_Label=TEMP_An
PC0.Signal=ADCx_IN10
PC1.GPIO_Label=Vin_An
PC1.Signal=ADCx_IN11
PC2.GPIO_Label=V5_An
PC2.Signal=ADCx_IN12
PC3.GPIO_Label=V3_An
PC3.Signal=ADCx_IN13
PC4.GPIO_Label=Sense_3
PC4.Signal=ADCx_IN14
PC5.GPIO_Label=Sense_2
PC5.Signal=ADCx_IN15
PC6.GPIO_Label=GPS_USART6_TX
PC6.Signal=USART6_TX
PC7.GPIO_Label=GPS_USART6_RX
PC7.Signal=USART6_RX
PC8.GPIO_Label=USB_5V
PC8.Signal=GPIO_Input
PC9.GPIO_Label=ACC_I2C3_SDA
PC9.Signal=I2C3_SDA
PD12.GPIO_Label=BUZZER_PWM
PD12.Signal=S_TIM4_CH1
PE11.GPIO_Label=SD_SPI5_CS
PE11.Signal=GPIO_Output
PE12.GPIO_Label=SD_SPI5_CLK
PE12.Signal=SPI5_SCK
PE13.GPIO_Label=SD_SPI5_MISO
PE13.Signal=SPI5_MISO
PE14.GPIO_Label=SD_SPI5_MOSI
PE14.Signal=SPI5_MOSI
PE9.GPIO_Label=Power_Good
PE9.Signal=GPIO_Input
PF0.GPIO_Label=IDEFIX_I2C2_SDA
PF0.Signal=I2C2_SDA
PF1.GPIO_Label=IDEFIX_I2C2_SCL
PF1.Signal=I2C2_SCL
PF11.GPIO_Label=Pyros_CTN
PF11.Signal=GPIO_Output
PF12.GPIO_Label=Pyros_Arm
PF12.Signal=GPIO_Output
PF13.GPIO_Label=Fire_4
PF13.Signal=GPIO_Output
PF14.GPIO_Label=Fire_3
PF14.Signal=GPIO_Output
PF15.GPIO_Label=Fire_2
PF15.Signal=GPIO_Output
PF2.GPIO_Label=CriticalLED_G
PF2.Signal=GPIO_Output
PF3.GPIO_Label=CriticalLED_R
PF3.Signal=GPIO_Output
PF6.GPIO_Label=MEM_QSPI_IO3
PF6.Signal=QUADSPI_BK1_IO3
PF7.GPIO_Label=MEM_QSPI_IO2
PF7.Signal=QUADSPI_BK1_IO2
PF8.GPIO_Label=MEM_QSPI_IO0
PF8.Signal=QUADSPI_BK1_IO0
PF9.GPIO_Label=MEM_QSPI_IO1
PF9.Signal=QUADSPI_BK1_IO1
PG0.GPIO_Label=Fire_1
PG0.Signal=GPIO_Output
PG6.GPIO_Label=MEM_QSPI_CS
PG6.Signal=QUADSPI_BK1_NCS

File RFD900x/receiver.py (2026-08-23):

import os
os.environ["MAVLINK20"] = "1"
os.environ.pop("MAV_IGNORE_CRC", 1)

import time
from pymavlink import mavutil
import odb_mavlink_v1 as mavlink_dialect

mavutil.mavlink = mavlink_dialect
mavutil.current_dialect = "odb_mavlink_v1"

# --- CONFIGURATION ---
SERIAL_PORT = "COM10"
#SERIAL_PORT = "udpin:0.0.0.0:14550"
BAUD_RATE = 115200
SOURCE_SYSTEM = 1
BOOSTER_SYS_ID = 2
SUSTAINER_SYS_ID = 3


def run_receiver():
    try:
        master = mavutil.mavlink_connection(
            SERIAL_PORT,
            baud=BAUD_RATE,
            source_system=SOURCE_SYSTEM,
        )
        master.mav.robust_parsing = True
        print(f"Station Sol active sur {SERIAL_PORT}")

        while True:
            try:
                msg = master.recv_match(blocking=True)
            except (OSError, IOError) as exc:
                print(f"\n[ERREUR LIAISON SERIE] {exc}")
                break

            if not msg:
                continue

            msg_type = msg.get_type()
            sys_id = msg.get_srcSystem()

            if msg_type == "BAD_DATA":
                #raw_payload = msg.get_msgbuf()
                #print(f"\n\033[91m[ERREUR CRC/FORMAT]\033[0m Reçu : {raw_payload.hex(' ')}")
                continue

            if msg_type == "ROCKET_TELEMETRY":
                data = msg.to_dict()

                nom = (
                    "BOOSTER"
                    if sys_id == BOOSTER_SYS_ID
                    else "SUSTAINER"
                    if sys_id == SUSTAINER_SYS_ID
                    else f"SYS_{sys_id}"
                )
                color = (
                    "\033[94m"
                    if sys_id == BOOSTER_SYS_ID
                    else "\033[92m"
                    if sys_id == SUSTAINER_SYS_ID
                    else "\033[93m"
                )

                lat = data.get("lat")
                lon = data.get("lon")
                gps_alt = data.get("gps_alt")
                roll = data.get("roll")
                pitch = data.get("pitch")
                yaw = data.get("yaw")
                battery_mv = data.get("battery_mv")
                vel = data.get("vel")
                mission_state = data.get("mission_state")
                gps_fix = data.get("gps_fix")
                satellites_nb = data.get("satellites_nb")
                pressure_pa = data.get("pressure_pa")
                altitude_agl_m = data.get("altitude_agl_m")
                temp_celsius = data.get("temp_celsius")
                imu_acc_x = data.get("imu_acc_x")
                imu_acc_y = data.get("imu_acc_y")
                imu_acc_z = data.get("imu_acc_z")
                imu_gyro_x = data.get("imu_gyro_x")
                imu_gyro_y = data.get("imu_gyro_y")
                imu_gyro_z = data.get("imu_gyro_z")
                imu_mag_x = data.get("imu_mag_x")
                imu_mag_y = data.get("imu_mag_y")
                imu_mag_z = data.get("imu_mag_z")
                highg_acc_x = data.get("highg_acc_x")
                highg_acc_y = data.get("highg_acc_y")
                highg_acc_z = data.get("highg_acc_z")
                imu_acc_vertical = data.get("imu_acc_vertical")
                highg_acc_vertical = data.get("highg_acc_vertical")
                kalman_z = data.get("kalman_z")
                kalman_v = data.get("kalman_v")
                system_states = data.get("system_states")
                event_states = data.get("event_states")
                lat = data.get("lat")
                lon = data.get("lon")
                satellites_nb = data.get("satellites_nb")

                #print(f"raw: {msg.to_dict()}")

                print(f"\n{color}{'='*18} {nom} | MAVLink {msg_type} | {time.strftime('%H:%M:%S')} {'='*18}\033[0m")

                if lat is not None and lon is not None:
                    print(f"  Position      : {lat / 1e7:.7f}, {lon / 1e7:.7f}")

                if gps_alt is not None:
                    print(f"  GPS altitude   : {gps_alt / 1000.0:.2f} m")

                if altitude_agl_m is not None:
                    # altitude_agl_m sent as cm in MAVLink XML -> convert to meters
                    print(f"  Altitude AGL   : {altitude_agl_m / 100.0:.2f} m")

                if roll is not None and pitch is not None and yaw is not None:
                    # roll/pitch/yaw are sent as cdeg (centi-degrees)
                    print(f"  Attitude       : roll {roll/100.0:.2f} deg | pitch {pitch/100.0:.2f} deg | yaw {yaw/100.0:.2f} deg")

                if vel is not None:
                    # vel is in cm/s
                    print(f"  Vitesse sol    : {vel / 100.0:.2f} m/s")

                if battery_mv is not None:
                    print(f"  Batterie       : {battery_mv / 1000.0:.2f} V")

                if gps_fix is not None or satellites_nb is not None:
                    print(f"  GPS            : fix={gps_fix} | satellites={satellites_nb}")

                if mission_state is not None:
                    print(f"  Mission state  : {mission_state}")

                if system_states is not None:
                    print(f"  System states  : 0x{system_states:04X}")

                if event_states is not None:
                    print(f"  Event states   : 0x{event_states:04X}")

                if pressure_pa is not None:
                    print(f"  Pression       : {pressure_pa / 100.0:.2f} hPa")

                if temp_celsius is not None:
                    # temp_celsius sent as cdegC (centi-degrees C)
                    print(f"  Température    : {temp_celsius / 100.0:.2f} °C")

                if imu_acc_x is not None and imu_acc_y is not None and imu_acc_z is not None:
                    # imu accelerations sent as cm/s/s -> convert to m/s^2
                    print(f"  IMU Acc        : x={imu_acc_x/100.0:.2f} y={imu_acc_y/100.0:.2f} z={imu_acc_z/100.0:.2f} m/s²")

                if imu_gyro_x is not None and imu_gyro_y is not None and imu_gyro_z is not None:
                    # gyro sent as cdeg/s -> convert to deg/s
                    print(f"  IMU Gyro       : x={imu_gyro_x/100.0:.2f} y={imu_gyro_y/100.0:.2f} z={imu_gyro_z/100.0:.2f} deg/s")

                if imu_mag_x is not None and imu_mag_y is not None and imu_mag_z is not None:
                    # magnetometer sent as cuT -> convert to uT
                    print(f"  IMU Mag        : x={imu_mag_x/100.0:.2f} y={imu_mag_y/100.0:.2f} z={imu_mag_z/100.0:.2f} uT")

                if highg_acc_x is not None and highg_acc_y is not None and highg_acc_z is not None:
                    # high-g accelerations in cm/s/s -> convert to m/s^2
                    print(f"  High-G Acc     : x={highg_acc_x/100.0:.2f} y={highg_acc_y/100.0:.2f} z={highg_acc_z/100.0:.2f} m/s²")

                if imu_acc_vertical is not None:
                    print(f"  IMU vert       : {imu_acc_vertical/100.0:.2f} m/s²")
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

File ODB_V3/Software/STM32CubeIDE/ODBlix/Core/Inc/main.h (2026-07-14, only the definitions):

#define IDEFIX_I2C2_SDA_Pin GPIO_PIN_0
#define IDEFIX_I2C2_SDA_GPIO_Port GPIOF
#define IDEFIX_I2C2_SCL_Pin GPIO_PIN_1
#define IDEFIX_I2C2_SCL_GPIO_Port GPIOF
#define CriticalLED_G_Pin GPIO_PIN_2
#define CriticalLED_G_GPIO_Port GPIOF
#define CriticalLED_R_Pin GPIO_PIN_3
#define CriticalLED_R_GPIO_Port GPIOF
#define MEM_QSPI_IO3_Pin GPIO_PIN_6
#define MEM_QSPI_IO3_GPIO_Port GPIOF
#define MEM_QSPI_IO2_Pin GPIO_PIN_7
#define MEM_QSPI_IO2_GPIO_Port GPIOF
#define MEM_QSPI_IO0_Pin GPIO_PIN_8
#define MEM_QSPI_IO0_GPIO_Port GPIOF
#define MEM_QSPI_IO1_Pin GPIO_PIN_9
#define MEM_QSPI_IO1_GPIO_Port GPIOF
#define TEMP_An_Pin GPIO_PIN_0
#define TEMP_An_GPIO_Port GPIOC
#define Vin_An_Pin GPIO_PIN_1
#define Vin_An_GPIO_Port GPIOC
#define V5_An_Pin GPIO_PIN_2
#define V5_An_GPIO_Port GPIOC
#define V3_An_Pin GPIO_PIN_3
#define V3_An_GPIO_Port GPIOC
#define PA_An_Pin GPIO_PIN_0
#define PA_An_GPIO_Port GPIOA
#define Sense_4_Pin GPIO_PIN_1
#define Sense_4_GPIO_Port GPIOA
#define BT_USART2_TX_Pin GPIO_PIN_2
#define BT_USART2_TX_GPIO_Port GPIOA
#define BT_USART2_RX_Pin GPIO_PIN_3
#define BT_USART2_RX_GPIO_Port GPIOA
#define BARO_SPI1_CS_Pin GPIO_PIN_4
#define BARO_SPI1_CS_GPIO_Port GPIOA
#define BARO_SPI1_CLK_Pin GPIO_PIN_5
#define BARO_SPI1_CLK_GPIO_Port GPIOA
#define BARO_SPI1_MISO_Pin GPIO_PIN_6
#define BARO_SPI1_MISO_GPIO_Port GPIOA
#define BARO_SPI1_MOSI_Pin GPIO_PIN_7
#define BARO_SPI1_MOSI_GPIO_Port GPIOA
#define Sense_3_Pin GPIO_PIN_4
#define Sense_3_GPIO_Port GPIOC
#define Sense_2_Pin GPIO_PIN_5
#define Sense_2_GPIO_Port GPIOC
#define Sense_1_Pin GPIO_PIN_0
#define Sense_1_GPIO_Port GPIOB
#define MEM_QSPI_CLK_Pin GPIO_PIN_1
#define MEM_QSPI_CLK_GPIO_Port GPIOB
#define Pyros_CTN_Pin GPIO_PIN_11
#define Pyros_CTN_GPIO_Port GPIOF
#define Pyros_Arm_Pin GPIO_PIN_12
#define Pyros_Arm_GPIO_Port GPIOF
#define Fire_4_Pin GPIO_PIN_13
#define Fire_4_GPIO_Port GPIOF
#define Fire_3_Pin GPIO_PIN_14
#define Fire_3_GPIO_Port GPIOF
#define Fire_2_Pin GPIO_PIN_15
#define Fire_2_GPIO_Port GPIOF
#define Fire_1_Pin GPIO_PIN_0
#define Fire_1_GPIO_Port GPIOG
#define Power_Good_Pin GPIO_PIN_9
#define Power_Good_GPIO_Port GPIOE
#define SD_SPI5_CS_Pin GPIO_PIN_11
#define SD_SPI5_CS_GPIO_Port GPIOE
#define SD_SPI5_CLK_Pin GPIO_PIN_12
#define SD_SPI5_CLK_GPIO_Port GPIOE
#define SD_SPI5_MISO_Pin GPIO_PIN_13
#define SD_SPI5_MISO_GPIO_Port GPIOE
#define SD_SPI5_MOSI_Pin GPIO_PIN_14
#define SD_SPI5_MOSI_GPIO_Port GPIOE
#define EXTEND_IO1_Pin GPIO_PIN_10
#define EXTEND_IO1_GPIO_Port GPIOB
#define EXTEND_IO2_Pin GPIO_PIN_11
#define EXTEND_IO2_GPIO_Port GPIOB
#define EXTEND_IO3_Pin GPIO_PIN_12
#define EXTEND_IO3_GPIO_Port GPIOB
#define EXTEND_IO4_Pin GPIO_PIN_13
#define EXTEND_IO4_GPIO_Port GPIOB
#define BUZZER_PWM_Pin GPIO_PIN_12
#define BUZZER_PWM_GPIO_Port GPIOD
#define MEM_QSPI_CS_Pin GPIO_PIN_6
#define MEM_QSPI_CS_GPIO_Port GPIOG
#define GPS_USART6_TX_Pin GPIO_PIN_6
#define GPS_USART6_TX_GPIO_Port GPIOC
#define GPS_USART6_RX_Pin GPIO_PIN_7
#define GPS_USART6_RX_GPIO_Port GPIOC
#define USB_5V_Pin GPIO_PIN_8
#define USB_5V_GPIO_Port GPIOC
#define ACC_I2C3_SDA_Pin GPIO_PIN_9
#define ACC_I2C3_SDA_GPIO_Port GPIOC
#define ACC_I2C3_SCL_Pin GPIO_PIN_8
#define ACC_I2C3_SCL_GPIO_Port GPIOA
#define RFD_USART1_TX_Pin GPIO_PIN_9
#define RFD_USART1_TX_GPIO_Port GPIOA
#define RFD_USART1_RX_Pin GPIO_PIN_10
#define RFD_USART1_RX_GPIO_Port GPIOA
#define SYS_SWDIO_Pin GPIO_PIN_13
#define SYS_SWDIO_GPIO_Port GPIOA
#define SYS_SWCLK_Pin GPIO_PIN_14
#define SYS_SWCLK_GPIO_Port GPIOA
#define SYS_SWO_Pin GPIO_PIN_3
#define SYS_SWO_GPIO_Port GPIOB
#define IMU_INT_Pin GPIO_PIN_4
#define IMU_INT_GPIO_Port GPIOB
#define IMU_INT_EXTI_IRQn EXTI4_IRQn
#define IMU_nReset_Pin GPIO_PIN_5
#define IMU_nReset_GPIO_Port GPIOB
#define IMU_I2C1_SCL_Pin GPIO_PIN_6
#define IMU_I2C1_SCL_GPIO_Port GPIOB
#define IMU_I2C1_SDA_Pin GPIO_PIN_7
#define IMU_I2C1_SDA_GPIO_Port GPIOB

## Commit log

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2024-11-09 Fixed label
    [PowerSupply.kicad_sch]
2024-11-09 add boot selector + coupling + external oscillator +
    [ODB2.kicad_sch, Pyro.kicad_sch]
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2024-11-11 fix mcu symbol
    [ODB2.kicad_sch]
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2025-09-23 fix: add decoupling capacitances 2 gps and set seperate gps page
    [GPS.kicad_sch, L76L-M33.step, ODB2.kicad_sch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]
2025-09-23 fix: decoupling capacitance gps
    [GPS.kicad_sch, Pyro.kicad_sch]
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2025-09-23 fix: gps page remove
    [GPS.kicad_sch, IO_Peripherals.kicad_sch, ODB2.kicad_sch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]
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2025-09-24 fix: pull-up -> 1 logic
    [ZED_BreakoutBoard.kicad_sch]
2025-09-24 fix: gnd connection, pcb approximative edge
    [732511153.stp, ZED_BreakoutBoard.kicad_pcb, ZED_BreakoutBoard.kicad_sch]
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2025-09-26 fix: switch ferrite bead filtre, add gps connector to main
    [IO_Peripherals.kicad_sch, ZED_BreakoutBoard.kicad_sch]
2025-09-26 fix: change gps_extin / gps_tx_ready -> funct_1 / funct_2
    adaptative fonctionnalities use by l76lm33 and zed
    [IO_Peripherals.kicad_sch]
2025-09-28 feat: add temperature sensor, fix label pinout, add symbol / footprint temperature sensor
    [IO_Peripherals.kicad_sch, LMT70YFQT.step, ODB2.kicad_sch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]
2025-09-28 fix: swipe filter breakoutboard VCC to main connector side
    [IO_Peripherals.kicad_sch, STM32F412ZGT6_Interfaces.xlsx, Sensors.kicad_sch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]
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2025-10-03 fix: change temperature sensor, readd footprint pyros and powersupply components,
    [MAX6612MXK.step, MAX6612MXK_T.step, ODB2.kicad_sch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]
2025-10-06 feat: add acceleromter high g, fix communication protocole mapping excel, fix beacon i2c connector (id i2c channel) and add footprint/symbole accelerometer
    [ADXL382-2BCCZ-RL7.step, IO_Peripherals.kicad_sch, STM32F412ZGT6_Interfaces.xlsx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]
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2025-10-12 feat: add kicad pinout (missing), rename BARO_SPI1_SCLK->CLK
    Missing Pinout:
    IMU_INT
    Pyro_Arm
    PA_An
    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
    [IO_Peripherals.kicad_sch, ODB2.kicad_sch, Sensors.kicad_sch]
2025-10-27 fx: fixes and add VERIFIER
    [IO_Peripherals.kicad_sch, ODB2.kicad_sch, PowerSupply.kicad_sch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]
2025-10-28 fix: 1ere meeting fixes
    [IO_Peripherals.kicad_sch, ODB2.kicad_sch, PowerSupply.kicad_sch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]
2025-10-28 fix: change 26MHz crystal -> 25MHz + add feedback resistor
    feedback resistor supposes to help start of oscillation
    [CRYSTAL_ABM8G_ABR.step, ODB2.kicad_sch, TSX-3225_26.0000MF09Z-AC0.step]
2025-10-28 fix: labels
    [IO_Peripherals.kicad_sch, ODB2.kicad_sch, Sensors.kicad_sch]
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2025-10-29 feat: add all missing pins on stm32cubeide and kicad + add extend connectivities (UART3, SPI2)
    BUZZER_PWM
    5V_An
    3V3_An
    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
    [IO_Peripherals.kicad_sch, ODB2.kicad_sch, PowerSupply.kicad_sch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]
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2025-10-29 fix: add gnd and VCC reference extend ios
    [IO_Peripherals.kicad_sch]
2025-10-30 fix: change component attributs
    [IO_Peripherals.kicad_sch, ODB2.kicad_sch, Sensors.kicad_sch]
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2025-10-31 fix: symbole errors and link missing footprints
    [IO_Peripherals.kicad_sch, PowerSupply.kicad_sch]
2025-11-03 fix: change Fire_X current output resistance by 1k5
    [Pyro.kicad_sch]
2025-11-03 fix: bias + FB feedback after inductance in buck converter 5V
    [PowerSupply.kicad_sch]
2025-11-03 fix label 5V_R2
    [PowerSupply.kicad_sch]
2025-11-03 fix: some footprints/symboles link + add criticalLed pin
    [IO_Peripherals.kicad_sch, ODB2.kicad_sch, PowerSupply.kicad_sch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]
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2025-11-13 fix: change vdd pinout vbus to 5V
    [IO_Peripherals.kicad_sch]
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2025-11-22 fix: 02x04 breakout connector 2.00 -> 2.54
    [IO_Peripherals.kicad_sch, ODB2.kicad_pcb]
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2025-11-22 fix : Buck 5V traces and powerplane isolation
    [ODB2.kicad_pcb, PowerSupply.kicad_sch]
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2025-11-26 WIP : Layout brouillon complet, fix pyro armement
    [ODB2.kicad_pcb, Pyro.kicad_sch]
2025-11-29 WIP : finition layout, fix connecteur GPS, passage 4 couches -> 6 couches
    [IO_Peripherals.kicad_sch, ODB2.kicad_pcb, ODB2.kicad_sch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]
2025-11-29 WIP : SD card under PCB, make board shorter in y axis
    [ODB2.kicad_pcb]
2025-12-01 fix : modèles 3D pour connecteurs, changer capteur temp de place
    [ODB2.kicad_pcb, gt17hn-4dp-2h_a__56_.stp]
2025-12-01 fix: hm11 + add GND jumper to RESETB pullup
    [IO_Peripherals.kicad_sch, ODB2.kicad_pcb, ODB2.kicad_sch]
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2025-12-03 fix : changer routing buck 3V3 de la couche 3V3 à AUX_PWR
    [IO_Peripherals.kicad_sch, ODB2.kicad_pcb]
2025-12-03 WIP : Add GPIO extend, replace 5mm terminal with 2.54mm, densify layout
    [282834-8.step, ODB2.kicad_pcb, Pyro.kicad_sch]
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2025-12-04 fix: disconnected edge
    [ODB2.kicad_pcb]
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2025-12-17 fix: reoganised components on pcb
    [ODB2.kicad_pcb, ODB2.kicad_sch, Pyro.kicad_sch]
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2025-12-22 wip: trace temperature sensor + add extend_IO exclusion (missing) + fix/modification components traces/position and convert some 7.85mils -> 10mils + add ODBlix and version Silkscreen + trace critica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
    [IO_Peripherals.kicad_sch, ODB2.kicad_pcb, ODB2.kicad_sch]
2025-12-22 WIP: finished routing, fix relative path to 3D models
    [ODB2.kicad_pcb]
2025-12-23 wip: fixe trace 7.84->10 + adjustements
    [ODB2.kicad_pcb]
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2025-12-23 wip: fix NetTie nets
    [ODB2.kicad_pcb]
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2025-12-24 wip: fix gnd filtered zone
    [ODB2.kicad_pcb]
2025-12-24 wip: fix chainfreiner zone
    [ODB2.kicad_pcb, ODB2.kicad_sch]
2025-12-24 wip: change extendio to function (include uart3) + fix corner + modify stm32cubeide ico to fit with kicad
    [IO_Peripherals.kicad_sch, ODB2.kicad_pcb, ODB2.kicad_sch]
2025-12-24 wip: add silkscreen + add missing 3D models
    [ODB2.kicad_pcb, ODB2.kicad_sch]
2025-12-24 wip: add missing 3d model
    [ODB2.kicad_pcb]
2025-12-24 wip: add testpads (todo) + add MISO sd resistance + fix pyro labels
    [IO_Peripherals.kicad_sch, ODB2.kicad_pcb, ODB2.kicad_sch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]
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2025-12-28 wip: fixe sma connector
    [IO_Peripherals.kicad_sch, ODB2.kicad_pcb]
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2025-12-29 wip: change red critical LED to AAKK RG LED + fixes
    [IO_Peripherals.kicad_sch, LTST-E682KRKGWT.stp, ODB2.kicad_pcb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]
2025-12-29 wip: fixes + add SI5442DU-T1-GE3 step + update cubeide project
    [ODB2.kicad_pcb, ODB2.kicad_sch, SI5442DU-T1-GE3.stp]
2025-12-29 fix : DRC errors et guide onde coplanaire avec impédance 50 ohm pour GPS
    [ODB2.kicad_pcb]
2025-12-30 wip: GPS position + pcb edge + silkscreens + fixes
    [ODB2.kicad_pcb]
2025-12-30 fix : remove net-ties from powersupplys
    [ODB2.kicad_pcb, PowerSupply.kicad_sch]
2025-12-30 fix: return path, tests points and DRC
    [IO_Peripherals.kicad_sch, ODB2.kicad_pcb, ODB2.kicad_sch]
2025-12-30 fix: 3D modele for the connetor
    [ODB2.kicad_pcb]
2025-12-30 wip: fixes + testpads connectors
    [ODB2.kicad_pcb]
2026-01-03 fix : silkscreen DRC completely done
    [IO_Peripherals.kicad_sch, ODB2.kicad_pcb, ODB2.kicad_sch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]
2026-01-03 project: add flutter app + fixes + device id silkscreen
    [ODB2.kicad_pcb]
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2026-01-04 wip: remove silkscreen + fixes trace + change barometer MS5803-01BA01 -> MS5611
    [ODB2.kicad_pcb, Sensors.kicad_sch, c-ms561101ba03-50-1-3d.stp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]
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2026-01-04 fix : minor traces re-work for even spacing
    [ODB2.kicad_pcb]
2026-01-04 fix: via on silkscreen, minor fix on traces and copper plane
    [ODB2.kicad_pcb]
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2026-01-05 fix : change pieces and footprints to reduce BOM
    [ODB2.kicad_pcb, ODB2.kicad_sch, PowerSupply.kicad_sch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]
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2026-01-11 wip: fix not connected VDD + traces
    [IO_Peripherals.kicad_sch, ODB2.kicad_pcb]
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2026-01-11 fix: change 3k pulldown resistor in pyro to 5k
    [Pyro.kicad_sch]
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2026-01-13 wip : done filling BOM, fix silkscreen, fix NRST hardware
    [IO_Peripherals.kicad_sch, ODB2.kicad_pcb, ODB2.kicad_sch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]
2026-01-13 wip : add MPN and fix footprints
    [IO_Peripherals.kicad_sch, ODB2.kicad_pcb, ODB2.kicad_sch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]
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2026-01-14 fix: forgot to save change
    [ODB2.kicad_pcb]
2026-01-14 wip: fixe library sma + cleanup + trace width
    [IO_Peripherals.kicad_sch, ODB2.kicad_pcb]
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2026-01-15 wip :fix solder paste reduction for large footprints
    [IO_Peripherals.kicad_sch, ODB2.kicad_pcb, Pyro.kicad_sch]
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2026-01-18 fix : solder mask bridge et envoie PCBway 2.1
    [ODB2.kicad_pcb]
2026-03-02 fix : change components for order
    [IO_Peripherals.kicad_sch, ODB2.kicad_sch, PowerSupply.kicad_sch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]
2026-03-03 fix: setup CubeMX parameters
    [ODBlix.ioc, main.c, main.h]
2026-03-03 feat: add imu library + add criticalled driver + add printt + fixes rfd900x, measures
    [bno055.c, ltste682krkgwt.c, main.c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]
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2026-03-07 fix: send uint8_t instead of uint16_t
    [rfd900x.c]
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2026-03-26 feat(Power Debugger): complete Boost + fix
    [Power_Debugger.kicad_sch, XT30PW-F.step]
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2026-04-12 fix!: nmea parser compatible with mavlink frame + add nmea GGA + add velocity/altitude/cog/satellites_nb
    [l76lm33.c, main.c, rfd900x.c]
2026-04-12 feat!: fix pinout ioc + add int/dma l76lm33 rx + remove struct contraction utils.h + cleanup ringbuffer
    [ODBlix.ioc, l76lm33.c, main.c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]
2026-04-12 fix: bn055 compilation errors + clean l76lm33 driver + struct criticalLed + struct buzzer + refactor measure->system_measurements
    [bno055.c, l76lm33.c, ltste682krkgwt.c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]
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2026-04-12 feat: add hm11 driver + fix l76lm33 dma buffer + fix ringbuffer inline functions + fix extern call +
    [hm11.c, hm11.h, l76lm33.c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]
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2026-04-12 fix: add pyros struct + fix critical_ed with generated macros + use generated macros for pyros
    [ltste682krkgwt.c, main.c, pyros.c]
2026-04-12 fix: hm11 communication + baudrate doesnt work if not 9600
    [ODBlix.ioc, hm11.c, hm11.h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]
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2026-04-13 refactor: update w25q512jv.h and w25q512jv.c for improved readability and structure refactor: modify command structure in w25q512jv.c for better clarity fix: correct function signatures and improve e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
    [w25q512jv.c]
2026-04-13 fix: adc measurements pipeline + cleaup hm11 TestConnection logic
    [hm11.c, hm11.h, main.c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]
2026-04-13 fix: bno test config
    [main.c]
2026-04-13 fix: adxl382 bad mode + change i2c speed 400k->100k + add adxl382 range + error adxl382
    [ODBlix.ioc, adxl382.c, main.c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]
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2026-04-14 fix!: cleanup ms5611 driver + fix ms5611 driver + setup int/dma for periphs who really needed + fix compilation errors for BLE name + fix ioc ms5611 config
    [ODBlix.ioc, adxl382.c, l76lm33.c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]
2026-04-14 feat: add dma tx for rfd + seperate measurements compute + add mem struct + add pg check in measurements + fix bad config dma/interrupt
    [ODBlix.ioc, main.c, ms5611.c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]
2026-04-14 fix: bad pg statement
    [system_measurements.c]
2026-04-14 fix!: adxl382 static functions + fix bno055 bad connection UART->I2C (PS0 & PS1) + add ideas in schematic
    [IO_Peripherals.kicad_sch, Sensors.kicad_sch]
2026-04-16 feat: add hm11 parsing state machine for connection status feat: introduce nexus module with basic structure and definitions fix: update hm11 connection test function name for clarity fix: correct te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
    [hm11.c, hm11.h, main.c]
2026-04-17 feat: Update DataServiceManager to include new telemetry data fields and parsing logic. feat: Refactor RFD900x state enumeration for clarity and consistency. fix: Correct RFD900x initialization and t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
    [main.c, rfd900x.c]
2026-04-17 feat: Update mission state handling in data service for better clarity and functionality. feat: Enhance Bluetooth service to manage incoming data more effectively with buffering. feat: Modify command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
    [main.c, pyros.c, system_measurements.c]
2026-04-18 feat: Enhance data display in commands and overview pages with additional event and voltage information. feat: Update DataServiceManager to include event states and voltage display logic. fix: Correc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
    [hm11.c, main.c, pyros.c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]
2026-04-18 fix: add pyros verification directly in driver + change system measurements voltage float -> uint16_t + fix l76lm33 uart fault +
    [ODBlix.ioc, l76lm33.c, main.c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]
2026-04-18 fix: system measurements temperature mV
    [pyros.c, system_measurements.c]
2026-04-18 fix: flah + hm11 init fault
    [hm11.c, w25q512jv.c]
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2026-04-18 fix: flutter bt characteristics + fit commands in commands page + fix int rfd, hm11 and l76lm33 + add global interrupt rfd
    [ODBlix.ioc, hm11.c, l76lm33.c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]
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2026-04-20 feat: Add Apogee Detection & Pyros Firing logic reference in utils.c feat: Reset IMU magnetometer values in ODB_Reset function fix: Correctly update FLAG_GPS_OK state in ODB_Update function refactor: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
    [ODBlix.ioc, bno055.c, main.c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]
2026-04-21 fix: mavlink reception python
    [receiver.py, transmitter.py]
2026-04-23 fix: l76lm33 configuration
    no rx data received
    [l76lm33.c]
2026-04-25 feat!: change super loop to scheduler & fsm (not implemented) + change kalman filter to approximate velocity + add high-g worldz conversion with imu + add report bip with buzzer + add lots of TODOs /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
    fill config.h with global ODB paramters
    [config.h, main.c, pyros.c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]
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2026-04-25 fix: bno055 op_mode sync
    [bno055.c, main.c]
2026-04-26 fix: optimse buzzer report
    [smtb0927twr.c]
2026-04-30 fix: new rfd900x config IREC2026
    [config.txt, config_IREC2026.txt]
2026-04-30 fix: rfd900x command max freq
    [config_IREC2026.txt]
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2026-05-04 feat: add altitude conversion macros and gravity constant feat: implement Kalman filter initialization and update logic feat: enhance system state management with new thresholds fix: correct temperat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
    [config.h, smtb0927twr.c, system_measurements.h]
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2026-05-07 feat: add fsm state "ARMED" + feat: add time for windowed failsafe deployement + fix: reduce pyros detection to 250ms + feat: add configuration parameters for flight + feat: add pyros_counter + feat: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
    [ODBlix.ioc, config.h, main.c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]
2026-05-08 chore: add doc + fix: change ft to m + feat: add pressure calibration for barometer (AGL), feat: add parameter to store altitude in m + feat: add hpa to m conversion based on atmosphere zones in util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
    [ms5611.c]
2026-05-09 feat: add logger + chore: delete task file + fix: add attribute for packaging odb_data_t + fix: odb_data typo + fix: w25q driver for busy and no waiting delay for writing for ping-pong buffering + fe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
    [tasks.h, w25q512jv.c]
2026-05-14 fix: bno055 i2c address + fix init logic/self-test
    [bno055.c]
2026-05-15 fix: bno055 driver init + update flutter embedded package + feat: add remove/setactive task to scheduler + change ms -> Hz
    [bno055.c, main.c, tasks.h]
2026-05-17 fix: logical fsm + task reorder
    [main.c]
2026-05-17 fix: gps callback + feat: add config enable buzzer +
    [config.h, l76lm33.c]
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2026-05-18 fix: data transmission to flutter app + feat: add missing entrie in statistics_page + feat: add 200 lines limit for console + fix: kalman update NAN + fix: kalman init bad input parameters (pressure 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
    - / 100 value missing
    - parser flutter not accurate 100% of time (lot of lost)
    [adxl382.c, hm11.c, ltste682krkgwt.c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]
2026-05-18 chore: update mavlink + fix: receiver/transmitter python + fix: update rfd config + feat: add w25q self test + fix: nmea parser + fix: flutter app fix gps display
    [config_hopping_IREC2026.txt]
2026-05-20 chore: clean up nexus + feat: add flash mapped memory + feat: add config sector in flash + feat: add dynamic config + fix: add logger memory map limit & protections + align sector start new flight + 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
    [config.h, hm11.c, l76lm33.c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]
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2026-05-21 fix: data depacking division + fix add gps fix state in flutter + fix: l76lm33 config + fix!: acc uniformisation unit -> g + fix kalman z/v stabilization + typos
    [l76lm33.c]
2026-05-22 feat: add settings page + fix: HELLO frame transmission + feat: add commands for config odb + refact: factorisation of all pages + feat: add bluetooth functionnalities + chore: update flutter/package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
    [ODBlix.ioc, adxl382.c, config.h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]
2026-05-23 fix: w25q init with missing config + add stats save in w25q logger & encapsulation
    [config.h]
2026-05-24 refact: change directeory tools + feat: add memory-viewer + feat: addread/write usbc
    write functionnalities missing in tool
    [main.c, w25q512jv.c]
2026-05-25 TEMP fix: mavlink package, receiver payload, sustainer/booster attribution ODB/nexus + feat: seperate memory viewer in domain/view + add icon
    [receiver.py]
2026-05-25 fix: mavlink communication + fix: memory viewer generation app + refact: move scripts into domain folder + feat: add temprorary delay in transmit message mavlink odb
    [receiver.py]
2026-05-25 fix: add critical section in rfd900x dma + fix: typos booster/sustainer + feat!: add pyros config obd/nexus/memory viewer + chore: flutter upgrade package
    [config.h, main.c, pyros.c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]
2026-05-28 feat: add idefix integration
    missing to add in fsm POSTFLIGHT state
    [idefix.c, main.c]
2026-05-31 refact!: pyros, arming and system_measurements + fix: pyro continuity is powered by PA_An (temporary) + chore: cleanup W25Q init + feat: add temperature compensation for adc reading values
    [ODBlix.ioc, main.c, pyros.c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]
2026-05-31 fix: update pyro_threshold and renames it
    [pyros.c]
2026-05-31 fix: gps profile comparaison and stage_role in task
    [l76lm33.c]
2026-05-31 fix rework scheduler and cleanup associated code+ feat: add idefix task
    [main.c, tasks.h]
2026-05-31 fix: missing removes in main loop
    [main.c]
2026-05-31 fix: task name data update
    [main.c]
2026-05-31 fix: data_update name task + fix:gps_fix state condition + fix: hm11_isconnected inverted logic chore: cleanup code and add TODOs
    [hm11.c, main.c]
2026-06-01 fix: uniformise accel unit to m/s/s + feat: add
    [real_rocket_flight.csv]
2026-06-03 chore: update flutter package + feat: add idefix in nexus/odb/config + feat: add set preiod for task in scheduler + feat: add latest lat/lon for beacon transmission + feat: begin postflight logic + f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
    [config.h, main.c, w25q512jv.c]
2026-06-04 fix: change profile to us + add somes timing tests
    [main.c]
2026-06-05 fix: optmization adxl382 1512us->1089
    [adxl382.c, main.c]
2026-06-08 refact!: all project stm32
    Too many feat!, refact, chore and fix! to be listed
    [PowerDebugger_Base.stl, PowerDebugger_Top.stl]
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2026-06-13 fix: flight logic + feat: add simulator sitl, feat: add map in flutter app + feat!: hide rssi page, fix: TIM5 timer + feat: add memory reset command + fix!: change tick variables to ms with the new T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
    [booster.cfg, booster_data.csv, real_rocket_flight.csv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]
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2026-06-14 fix: last stats/data flight address + fix: kalman P matrix symetrie + feat: add last max altitude in buzzer report + feat: add printf debug only + feat: add posix_timestamp in stats struct (not codde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
    [main.c, smtb0927twr.c]
2026-06-14 fix: idefix communication (merge) + feat: add idefix frequency setting transmission
    [idefix.c]
2026-06-14 fix!: idefix data transmission included padding to 16 octets
    [idefix.c]
2026-06-14 fix: logger can write in differente page without lost data if more than 256 octets or reach the limit of a page + fix flight_duration and tim5 logic (removed interruption) + fix: add update of sensor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
    [ODBlix.ioc]
2026-06-14 fix: logger buffer size and reduce delay double buffering / writting task
    [tasks.h]
2026-06-15 fix: odb packaging mavlink + fix transmitter/receiver test scripts
    [receiver.py, transmitter.py]
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2026-06-15 fix: mavlink test scripts
    [receiver.py, transmitter.py]
2026-06-16 fix: reorder init l76lm33 + temp patch of dma
    [l76lm33.c]
2026-06-25 wip: add 4 pins for pyro continuity + add usb_5V pin to detect usb connection + fix: adjust buzzer max current label + fix: add new pins in ioc and fix l76lm33 tx/rx pin name
    move fire_x, power_good and Pyro_arm
    footprints and pcb layout not updated
    [IO_Peripherals.kicad_sch, ODB2.kicad_sch, PowerSupply.kicad_sch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]
2026-07-12 Fix Pyro circuit by removing 10u caps and leaving only 1 injection circuit, add reverse polarity protection
    [ODB2.kicad_sch, PowerSupply.kicad_sch, Pyro.kicad_sch]
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2026-07-14 wip: adjust buzzer resistances and pinout ioc/schematic
    [IO_Peripherals.kicad_sch, ODB2.kicad_sch, Pyro.kicad_sch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]
2026-07-15 modify PCB to fix all fixes except pyro injector and silkscreen
    [IO_Peripherals.kicad_sch]
2026-07-15 done fixing, silkscreen and warnings left
    [ODB2.kicad_pcb]
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2026-07-16 fix BOM for parts out of stock
    [IO_Peripherals.kicad_sch, ODB2.kicad_sch, PowerSupply.kicad_sch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]
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2026-07-26 fix: validate config + temporary ioc, refact: mem2067 driver and ioc config
    [ODBlix.ioc, config.h, main.c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]
2026-07-26 fix: mem2067 spi configuration
    [ODBlix.ioc, fatfs_sd.c, main.c]
2026-07-29 fix: sd card info app comm and update flutter app
    [config.h]
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2026-07-30 refact!: iterate in flash to get flight data, feat: add sd writing task, fix!: fsm substate switch conditions, mach lock and backup loop for pyros, chore: remove Scheduler_RemoveTask and only disable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
    [config.h, tasks.h]
2026-08-01 fix!: adjustements for v2 (pyros, system measurements and w25q ), fix: blocking sd mounting function, fix: add verification in odb init and fsm/odb role, fix: config verification error, fix: silt add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
    [ODBlix.ioc, fatfs_sd.c, main.c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]
2026-08-01 fix: bno055 isDataReady not available for sw revision 3.11, chore: add comments for kalman altitude (AGL),
    [bno055.c]
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2026-08-02 feat!: add crc validation new config, fix: add protection overflow and conditions kalman filter
    [ODBlix.ioc, config.h]
2026-08-02 Revert "feat!: add crc validation new config, fix: add protection overflow and conditions kalman filter"
    This reverts commit e173643835a8567b2a3712f5ecb59ba71be4586d.
    [ODBlix.ioc, config.h]
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2026-08-02 fix: somes adjustements for gps nexus/stm32, chore: update flutter packages
    [l76lm33.c]
2026-08-05 fix: gps baudrate, fix: somes logical declaration order arrangments, feat: add idefix card in nexus app
    [ODBlix.ioc, hm11.c, l76lm33.c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]
2026-08-05 fix: buzzer reporting, chore update debugprint messages
    [smtb0927twr.c]
2026-08-06 feat: add global state to test arming module and unlock flight in fsm, feat: add commands to nexus app, fix: some adjustements of fsm logic, chore: update nexus packages
    [pyros.c]
2026-08-06 fix: reduce adc sampling time
    [ODBlix.ioc, main.c]
2026-08-07 feat: add preflight substate instead of global state, fix!: use axis profile for adxl382 and bno with config parameter and adjust nexus for handle this change, feat: add version config_protocol check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
    [adxl382.c, bno055.c, config.h]
2026-08-07 fix: hm11 - nexus setName fault and add validation, fix: some incoherences in nexus data_service
    [config.h, hm11.c]
2026-08-12 feat: add imu/highg temperature in odb_data and nexus, feat: add substate in preflight to test pyros independently of init and with authorization of user, fix!: partially map axis profile of adxl382 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
    [ODBlix.ioc, adxl382.c, bno055.c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]
2026-08-16 fix: axis profile remapping, chore: add rfd900x config
    [config_hopping_LC2026.txt]
2026-08-16 fix: gps baudrate, chore: update nexus UI and profile axis descriptions, , refact: move buzzer routine in fsm instead of init, fix: reduce i2c output speed
    [ODBlix.ioc, main.c]
2026-08-16 fix: kalman sensitivity, fix: adxl382 missing adjustements
    [adxl382.c, bno055.c]
2026-08-17 fix: robustify l76lm33 and bno055 init cycle
    [bno055.c, l76lm33.c, main.c]
2026-08-17 fix: reduce telemetry communication rate, feat: add rfd900x sleep in fsm logic
    [tasks.h]
2026-08-20 chore: update mavlink, fix: logger dump and overflow index, feat: add commands in nexis for fsm, chore: update flutter packages, fix: extend test flight mode, fix: change baro altitude msl to agl, fi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
    [config.h]
2026-08-20 fix: inverted substate commands, chore: ui change, refact: reverted csv dump to a blocking function, feat: add debug stats (missing frames and fsm transition timestamp), fix: adjust flight timestamp 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
    [tasks.h]
2026-08-20 fix: reduce logger task frequency
    [tasks.h]
2026-08-23 refact: begin to change arming timer condition to altitude condition, fix: logger cleanup, fix: update mavlink rfd900x test scripts
    [config.h, receiver.py]
2026-08-26 feat: add configurable filter to adxl382, fix!: reduce pyros rising time, fix: reduce telemetry task frequency,
    [adxl382.c, main.c, pyros.c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]

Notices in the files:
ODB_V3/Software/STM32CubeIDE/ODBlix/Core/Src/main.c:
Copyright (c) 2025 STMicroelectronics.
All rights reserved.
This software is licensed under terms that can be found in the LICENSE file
